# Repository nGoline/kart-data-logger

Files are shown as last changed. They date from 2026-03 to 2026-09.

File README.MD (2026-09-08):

# ESP32 Kart Telemetry System

A telemetry and datalogging system for open-track go-karts, built around a single
steering-wheel-mounted ESP32 display board that handles everything: GPS
acquisition, lap timing, dashboard rendering and SD logging.

> **Note:** earlier revisions of this project split the work between a
> helmet-mounted logger node and the display, linked over ESP-NOW. That helmet
> node proved unreliable at the track and has been removed — the display is now
> the only node.

## System Architecture

Single target: the **Display Dashboard Node**.

* **Board:** JC3248W535N (ESP32-S3, AXS15231B QSPI panel)
* **Role:** GPS acquisition, lap detection, UI dashboard, and SD logging.
* **Features:**
  * GPS from ATGM336 (default) or u-blox M9, wired directly to the board.
  * Live speed, G-force, satellite count and display battery state.
  * Finish-line based lap detection with best/previous lap deltas.
  * Telemetry logged to SD card per recording session.
  * Optional MPU6050 IMU for speed filtering and steering angle.

### Build targets in `platformio.ini`

Both targets build the same application (`src/main_display.cpp`) and differ only
in the panel driver backend:

* `env:display_gfx` — Arduino_GFX backend (`lib/DisplayGFX`). **Default.**
* `env:display` — esp_lcd backend (`lib/DisplayBSP`). Fallback.

The Arduino_GFX backend is the default because it resolves a QSPI panel wedge
seen with the esp_lcd path.

## Key Technical Features

* **Modular GPS provider** abstraction in `GpsManager`.
* **Finish-line lap detection** in `LapManager`, driven by GPS position.
* **`fix_stride.py` prebuild patch** for SquareLine Studio LVGL 9 image exports.
* **Display-wedge watchdog** — a 5s task watchdog on `loopTask` turns a panel
  wedge into a fast auto-reset instead of a permanent freeze.
* **Charge mode** to keep the board from eating the charger's current budget.
* **Optional IMU support** to improve speed filtering and live telemetry.

## Charge mode

The charger's current is shared between the board and the cell, so a running
dashboard slows charging considerably. Charge mode parks the device:

* Stops the recording session and closes the GPS UART.
* Drops the CPU to 80 MHz (the floor for stable USB-CDC — don't go lower).
* Swaps to a minimal charge screen and blanks the backlight after 15s.

It is **only ever entered manually**, from the `CHARGE MODE` button on the
config screen. Nothing enters it automatically, so bench testing and debugging
are unaffected.

While parked: tap anywhere to wake the backlight and read the battery for
another 15s; press `RESUME` to leave. Resuming re-probes the GPS, which takes a
couple of seconds.

> **Whether the GPS actually sleeps depends on which one is fitted.** Charge mode
> calls `gps.standby()` and leaves the UART open so `wake()` can talk to it.
> On the **ATGM336** that is a quiesce, not a sleep: the RF front end has no
> software power-down at all, so it keeps drawing ~25-40 mA and standby only cuts
> it to GPS-only at 1Hz with NMEA muted. On the **u-blox M9** it is a real
> power-down — `UBX-RXM-PMREQ` software backup, woken by traffic on the module's
> RX pin. Coming back may cost a cold start if the module's V_BCKP does not hold
> the BBR, but the configuration itself is in flash and survives either way.

> **The percentage reads high while charging.** With no power-path charger the
> sense divider sits on the charger rail, so it measures the cell terminal
> voltage *under charge*, which is well above its resting value — expect a
> jump downward when you unplug. It's shown as `~94%` to mark it approximate;
> the voltage below it is the number to trust.

The charge screen and the config-screen button are both built at runtime in
`lib/UiHelper/uiHelper.cpp` rather than exported from SquareLine, so
re-exporting `lib/ui/` will not wipe them.

## Hardware Requirements

* JC3248W535N display board
* GPS module wired to `RX=6` / `TX=7` — ATGM336, or a u-blox M9 such as the Matek
  M9N-5883. The ATGM336 runs on 3V3; the M9N-5883 wants 4~5.5V, so its VCC belongs
  on the IP5306 5V rail, not the board's 3V3.
* Optional MPU6050 IMU
* microSD card formatted FAT32

## Software Dependencies

Built with PlatformIO.

* `lvgl/lvgl` (v9.x)
* `moononournation/GFX Library for Arduino` (`display_gfx` only)
* `mikalhart/TinyGPSPlus`
* `ElectronicCats/MPU6050`

## GPS Providers

`GpsManager` supports two providers. Nothing older than these is supported — the
NEO-6M-era 9600-baud fallback is gone.

* **ATGM336 provider** (current default)
  * Enabled with `-D GPS_PROVIDER_ATGM336`.
  * 10Hz.
  * Configured over CASIC text commands (`$PCAS`), which are never acked, so the
    module cannot report whether a setting took. It also cannot be put to sleep:
    `$PCAS12` standby is a 5L-only feature and this is a 5N.
* **u-blox M9 provider** — targets the M9 generation (NEO-M9N), e.g. the Matek
  M9N-5883.
  * Leave `-D GPS_PROVIDER_ATGM336` out of the build flags.
  * 25Hz.
  * Probes 115200 then 38400 (the M9 default), and moves the port to 115200.
  * Sleeps for real in charge mode — `UBX-RXM-PMREQ` software backup, armed to
    wake on UART RX traffic.
  * Configured over binary UBX, which *is* acked, and the provider reads the
    dynamic model / rate / power mode back at boot and logs `BEFORE:` and
    `AFTER:` lines. Legacy `UBX-CFG-*` messages are deprecated on generation 9
    but still supported; they are removed on generation 10, so a future module
    means porting `configureUblox()` to `UBX-CFG-VALSET`.
  * **Speaks `UBX-NAV-PVT`, not NMEA.** All NMEA output is disabled. One 92-byte
    frame per epoch carries position at 1e-7° (~1.1cm), Doppler ground speed,
    UTC, `numSV`, `fixType`, `pDOP`, `hAcc` and `sAcc` — less traffic than
    GGA+RMC and strictly more information, as one coherent snapshot instead of a
    position from one sentence stitched to a speed from another. It also makes the
    four-constellation problem vanish: per-system duplication of GSA/GSV was an
    NMEA artefact, and UBX has no talker IDs to multiply.
  * `hasFix()` therefore uses the receiver's own verdict — `gnssFixOK`,
    `fixType == 3`, and `hAcc` within bounds — rather than the `sats >= 4 &&
    HDOP <= 3` heuristic the NMEA path had to guess with.
  * **TinyGPSPlus is unused on this path.** It stays in `lib_deps` for the
    ATGM336, and static-archive linking drops it (and the unreferenced provider)
    from the image. It is still compiled every build, so a break in either
    provider still fails the build.

The flag lives in `[display_common] -> build_flags_base`, so it applies to both
build targets at once.

### Fix rate

ATGM336 runs at **10Hz**, u-blox M9 at **25Hz** — the receiver's ceiling with all
four constellations. GGA+RMC at 25Hz is ~36kbaud of the 115200 the port is set to,
so the link has room to spare. 40ms epochs also land on exact centisecond values
(`.00`/`.04`/`.08`…), which matters because NMEA timestamps are centiseconds and
anything finer would round.

The rate buys **log resolution**, which is the point — at 100 km/h, 25Hz puts a
sample every 1.1m instead of every 2.8m. It buys much less for lap times, because
`LapManager` intersects the finish gate with the segment between consecutive fixes
and interpolates the crossing millisecond along it, so the reported time never
quantised to the fix interval in the first place.

To sustain 25Hz, `LogManager` holds the log file open for the whole session and
`flush()`es once a second, rather than reopening and closing it per row (25 FAT
directory updates a second is where a slow card starts stalling). The trade is
durability: an abrupt power-off now costs up to a second of the lap instead of a
single sample. The telemetry queue is 40 frames for the same reason — ~1.6s of
headroom at 25Hz, so a card stall doesn't drop rows.

### GPS wiring

The GPS UART pins are set by `GPS_STANDALONE_RX` / `GPS_STANDALONE_TX` in
`[display_common]`, currently `6` and `7`.

Watch for collisions when changing these: `GPIO5` carries the battery sense
divider (`DISPLAY_BATT_ADC` in `src/main_display.cpp`), and `GPIO18`/`GPIO17`
are the IMU's I2C pins when `ENABLE_IMU` is set.

## Session button

A momentary switch wired between `SESSION_BUTTON_PIN` and GND starts and stops
recording without touching the screen — the dash is on the steering wheel and the
touch target is small with gloves on.

* **Tap** — runs the same start gesture as the on-screen START button: the
  full-screen 3-2-1 overlay with the track name and a CANCEL, then the session
  begins (GoPro rolls, active track's finish line re-applied).
* **Hold 3 s** — stops it, counting `3 - 2 - 1` on the dashboard. Let go early and
  nothing happens.

The start overlay is parented to whatever screen is showing rather than to the
config screen, so it is visible when the physical button fires it from the
dashboard. Tapped from the config screen those are the same object, so the
on-screen button is unchanged.

The button is inert in charge mode — `loop()` returns before the display lock is
taken there, which is the point of that mode.

A tap while a session is already running does nothing: stopping is deliberately
the harder gesture, since an accidental stop costs the rest of the session.

Configured in `platformio.ini`:

| Flag | Default | Notes |
|---|---|---|
| `SESSION_BUTTON_PIN` | `6` | Comment out to build without a button |
| `SESSION_BUTTON_HOLD_MS` | `3000` | Hold time for the stop |
| `SESSION_BUTTON_ACTIVE_HIGH` | off | Set when the switch goes to 3V3 rather than GND |
| `SESSION_BUTTON_DEBOUNCE_MS` | `25` | Raise it if a long lead registers phantom taps |

Wire the switch between the pin and **GND** by default. If the spare wire in the
loom is a 3V3 instead, wire it pin-to-3V3 and set `SESSION_BUTTON_ACTIVE_HIGH` —
that swaps the internal pull-up for a pull-down, so the idle level is still the
released one. The pin is pulled to the idle rail either way and never left
floating: a floating input on a wire run out to a steering wheel picks up enough
to toggle on its own, and a broken wire then reads as *released* rather than as a
stuck press.

GPIO 6 is the ATGM336's old RX pad, already broken out and in the loom now that
the GPS is on 17/18. Other free pins: 7, 9, 10, 14, 15, 16, 41, 42. Avoid 0, 3,
45, 46 (strapping), 19/20 (native USB), 43/44 (UART0) and 26-37 (flash/PSRAM).

The state machine (`lib/SessionButton`) holds no GPIO or LVGL state, so it is
replayed on the host by `tools/lapreplay/sessionbutton.cpp` — bounce windows, a
release a millisecond short of the hold, and the `millis()` wrap, none of which
can be produced reliably with a thumb.

## Filesystem & Storage

The display reads and writes to a **FAT32 microSD** card. No files need to be
pre-populated — the display creates what it needs on first boot — but the files
below may be edited on a computer for configuration.

#### `/config.ini` (auto-created)

Stores display preferences. Created with defaults on first boot if absent.

```ini
# Kart Data Logger Configuration
theme=dark          # dark | light
selected_track=0    # index into tracks.ini
```

#### `/health.csv` (auto-created, only when something goes wrong)

Appended across every session, one row per second in which the telemetry queue
had no room for a frame:

```
epoch,log,dropped_total,dropped_delta
```

**An empty or absent file is the good news** — it means no row was ever lost. Any
row in it means the card could not keep up with the fix rate and the matching
`log_N.csv` is missing samples, so the file is worth checking after a race rather
than watching the serial log, which is unreachable with the dash on a wheel.

`epoch` comes from the GPS-synced system clock, so it lines up with the `epoch`
column in the telemetry file; before the first fix it degrades to uptime.

#### `/tracks.ini` (optional, user-created)

Defines named tracks with GPS finish-line coordinates. The display reads this at
boot and populates the track selector in the UI. If absent, no tracks are
preloaded.

```ini
# Kart track configurations
count=2

0_name=Kartódromo Granja Viana
0_left_lat=-23.60488969
0_left_lon=-46.83622658
0_right_lat=-23.60493793
0_right_lon=-46.83641597

1_name=My Track
1_left_lat=0.00000000
1_left_lon=0.00000000
1_right_lat=0.00000000
1_right_lon=0.00000000
```

#### `/log_N.csv` (auto-created per session)

Telemetry session logs. A new numbered file is created each time a recording
session starts.

```
epoch,speed,totalGForce,gForceX,gForceY,steering_angle,sats,lat,lng,fix,pdop,hacc,sacc
```

The last four are the receiver's report on its own fix, and are **zero on the
ATGM336** — NMEA carries no equivalent, so zero means "not reported", not "perfect".

| column | meaning |
| --- | --- |
| `fix`  | `0` no fix, `2` 2D, `3` 3D, `5` time only. Never `1`/`4` (dead reckoning) — that is NEO-M9V silicon, not M9N. |
| `pdop` | position dilution of precision |
| `hacc` | horizontal accuracy estimate, metres, ~1σ |
| `sacc` | speed accuracy estimate, m/s |

`hacc` is the useful one for analysis: it does not make a position better, it tells
you which samples to distrust. Around 0.7-1.5m under open sky, climbing near
buildings and in the first seconds after a cold start. A lap time interpolated
between two 12m samples is not a lap time to trust to hundredths.

These columns are **appended**, never inserted, so everything in `tools/` keeps
working — those read by column name or by a fixed `sscanf` prefix. A CSV derived
from GoPro footage simply lacks them.

Note `lat`/`lng` are written at 7 decimal places (~1.1cm) rather than 6 (~11cm),
which is what `UBX-NAV-PVT` actually resolves.

## Setup & Installation

1. Clone this repository.
2. Open it in VSCode with PlatformIO.
3. Edit the UI using the SquareLine Studio project files in `UIDesign/`.
4. Export the UI to `/lib/ui/` and let `fix_stride.py` patch LVGL image metadata during build.
5. Flash the firmware: `tools/flash.sh` (see below).
6. Insert a FAT32 microSD card into the display. A default `config.ini` is created on first boot.

### Flashing

`upload_port` in `platformio.ini` is pinned to `/dev/cu.usbmodem1101`, which is one
machine's enumeration — the same board comes up under a different name elsewhere and
`pio run -t upload` then fails on a port that isn't there. `tools/flash.sh` finds the
board by USB `VID:PID` instead and passes it with `--upload-port`, which overrides the
pinned value:

```bash
tools/flash.sh              # default env, confirm, then upload
tools/flash.sh -m           # ...and open the serial monitor afterwards
tools/flash.sh -e display   # the esp_lcd fallback env
tools/flash.sh -p /dev/cu.usbmodem101   # skip discovery
tools/flash.sh -y           # no confirmation prompt (also FLASH_YES=1)
tools/flash.sh -- -v        # anything after -- goes to `pio run`
```

Before uploading it prints the port, env and `FW_VERSION`, and warns if the tree is
dirty — `FW_VERSION` is `git describe --tags --always --dirty` and shows on the setup
screen, so it is easy to flash uncommitted edits by accident. If more than one board is
attached it lists the candidates and asks for `-p`.

`pio run -e display_gfx -t upload` still works if the pinned port happens to be right.

## Dormant libraries

These libraries are no longer part of the build — nothing includes them — but
they are kept in `lib/` because they may be useful again:

* `EspNowManager` + `Shared/EspNowProtocol.h` message types — the board-to-board radio link.
* `ErrorLogManager` — LittleFS error capture and transfer.
* `AudioManager`, `VoiceParser` — I2S playback and spoken number/lap announcements.
* `PowerManager` — button-driven hibernate and power gating.
* `FakeGps` — CSV replay for development without GPS hardware.

`Shared/EspNowProtocol.h` is still compiled: `TelemetryMsg` is the record the
display passes between the UI, the lap manager and the SD log task.

## Design files

Design files are included under the `hardware/` folder.

### 3D Models

I've used Fusion to design 3D models for the custom enclosures and mounts. These
are located in `hardware/3d-models/` and exported as `.f3d` and `.3mf` files.
You can open and modify these in Fusion or any compatible 3D modeling software.

## Visual Reference

The repository includes module photos in the `images/` folder.

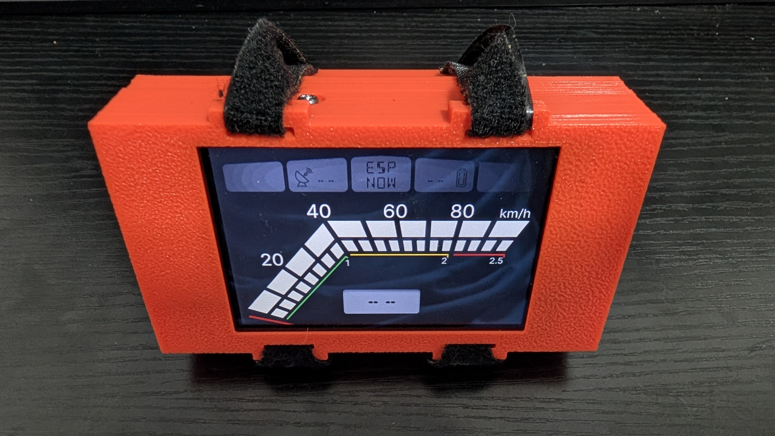
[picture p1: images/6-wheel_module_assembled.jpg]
Wheel module assembled


## Notes

* The display firmware owns the whole pipeline: GPS, lap timing, UI and SD logging.
* Lap detection only runs while a recording session is active.

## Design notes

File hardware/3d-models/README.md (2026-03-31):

# 3D Models

This folder contains the Fusion 360 source models and assembly exports used to validate the kart display enclosure and its subcomponents.

## Included files

* `Display.f3d` — main display enclosure model.
* `Display Assembly.3mf` — assembly export showing how the display, rear cover, battery support, and wheel holder fit together.
* `Battery.f3d` — battery pack model and holder details.
* `4056 Battery Charger.f3d` — USB-C charging board model and placement.
* `GPS.f3d` — GPS enclosure model.
* `MP6050.f3d` — IMU module model.

## Design intent

The primary part is `Display.f3d`. The other models were created to build the assembly and verify that all pieces fit correctly.

## Mounting and fastening

* The display board is held in place by small pegs that fit into matching bosses in the enclosure.
* The back cover is pressed onto the display body by rear cover pegs and then bolted in place.
* The back cover uses eight `M3X3X5` heat inserts and eight `M3x6` bolts.
* The helmet GPS enclosure uses four `M2.5x6mm` bolts and four `M2.5x4x4mm` heat inserts.
* The GPS holder fits the ATGM336 module and a `25x25mm` antenna.

## Battery and charging

* The rear cover supports a `LGBH4ZB4857` 2000mAh battery.
* The battery is sourced from a Dell Latitude 5490 battery pack, which contains three of these cells.
* A `4056` 1A USB-C charging board is integrated into the back cover space.

## Wheel holder and battery cover

* The battery cover / wheel holder assembly is not permanently fixed to the back cover.
* It is held in place by velcro loops that attach from the front of the display case, securing the assembly without rigid fasteners.
* The wheel holder is fixed to the rear plate using four `M3X3X5` heat inserts and four `M3x6` bolts.
* This wheel holder section can be modified for different kart wheel sizes, or multiple sizes can be printed and swapped without redesigning the entire case.

## IMU placement

* The IMU is mounted to the front of the battery back plate using double-sided tape.

## Notes

* Use the Fusion 360 `.f3d` files for source edits and design updates.
* The `.3mf` assembly file is useful for fit verification and export to compatible printing workflows.
* Confirm fastener lengths and insert positions before printing if you modify the enclosure geometry.

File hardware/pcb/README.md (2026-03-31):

# PCB Documentation

This folder holds PCB design documentation for the kart telemetry system.

There are two PCB variants documented here:

* `hardware/pcb/SMD/README.md` — the surface-mount device (SMD) PCB version.
* `hardware/pcb/Perfboard/README.md` — the through-hole perfboard version.

Use this root README as the entry point for the PCB designs and follow the subdirectory README files for variant-specific details.

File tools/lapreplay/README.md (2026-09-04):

# Lap replay harness

Offline test rig for finish-line detection. Turns a GoPro's telemetry into the
logger's own CSV format and replays it through the **real** `lib/LapManager`
compiled for the host — so lap detection can be validated without going to the
track.

Nothing here is part of the firmware build. `tools/` is outside `build_src_filter`
and `lib/`, so PlatformIO never sees it.

`make` also builds **`delta`**, which checks the *live* lap delta: the number
the dash hero panel shows continuously, from matching each fix against a
reference lap's recorded trace. See "Testing the live delta" below.

`make` also builds **`navpvt`**, an offset-level check on the real
`UbloxGpsProvider::update()` — it feeds synthetic `UBX-NAV-PVT` frames through a
byte-queue serial stub and asserts what the provider decodes. Run it after touching
that provider: it decodes by explicit byte offset, and a wrong offset does not crash,
it produces plausible telemetry that is silently wrong. It covers the field offsets,
the `hasFix()` gates (2D rejected, `hAcc` bound), checksum rejection, mm/s→km/h
scaling, and a frame split at every byte boundary — that last one being the real 25Hz
failure mode, where a message straddles two `update()` calls because the UART buffer
drained mid-frame.

## Why a GoPro

GoPro MP4s carry a GPMF metadata track alongside the video. On a HERO8 that is
GPS at ~18 Hz and accelerometer/gyro at ~200 Hz — denser than the ATGM336's
10 Hz, already timestamped in UTC, and free if you were filming anyway.

## Usage

```sh
# 1. extract telemetry -> CSV (no ffmpeg/exiftool needed; parses the MP4 directly)
python3 gpmf_to_csv.py ../../video/GH011973.MP4 GH011973.csv

# 2. build the harness
make

# 3. replay against a finish line: <csv> <leftLat> <leftLng> <rightLat> <rightLng>
./replay GH011973.csv -23.60488969 -46.83622658 -23.60493793 -46.83641597
```

`make VERBOSE=1` surfaces `LapManager`'s own `log_d()` gate diagnostics
("Approaching Gate", "Gate Missed!", "VALID CROSSING") which are compiled out by
default.

### Testing lap *timing*

A single crossing only starts the clock — it produces no lap time. If the clip is
a near-closed loop, stitch it into synthetic laps:

```sh
python3 gpmf_to_csv.py ../../video/GH011973.MP4 looped.csv --repeat 4
./replay looped.csv -23.60488969 -46.83622658 -23.60493793 -46.83641597
```

Each reported lap should equal the printed span exactly; any drift is a bug in
the crossing interpolation.

### Testing the live delta

The hero panel's delta comes from `LapManager`'s reference trace: the lap in
progress is recorded as position plus elapsed time, the session's best lap is
kept as the reference, and every fix is matched to the nearest point on it. A
wrong match does not crash, it produces a plausible number that is quietly
attached to the wrong piece of track, which is the worst way to find out at a
circuit. `delta` catches that offline:

```sh
python3 gps_raw_to_log.py --out /tmp/session.csv ../data/gps_raw_GH0*1974.csv
./delta /tmp/session.csv -23.605392 -46.836045 -23.605442 -46.836251
```

The `err` column is the check. At the line the live delta must agree with the
arithmetic one (this lap's time minus the reference lap's), because the two are
the same comparison reached by completely different routes: one by matching
1,000-odd fixes against a polyline, the other by subtracting two crossing
timestamps. On the 12-lap fixture they agree to within 22 ms on every lap, and
the harness exits non-zero if any lap drifts past 250 ms.

`moves` and `held` say how many fixes changed the number and how many repeated
it. A delta that "moves" once per lap would be the old behaviour, and the
point of the whole feature is that it does not. `--dump` emits
`epoch,lap,elapsed_ms,delta_ms` per fix for plotting the trace of a lap.

The trace buffers are allocated by the caller, here and in the firmware, which
is what lets `LapManager` stay host-clean: on the dash they come from PSRAM, in
this harness from `new[]`.

## Column mapping

Output matches `LogManager::task`'s `/log_N.csv` exactly:

```
epoch,speed,totalGForce,gForceX,gForceY,steering_angle,sats,lat,lng
```

| column | source | notes |
|---|---|---|
| `epoch` | `GPSU` | absolute UTC, 1 Hz; the 18 Hz `GPS5` samples are interpolated between stamps |
| `speed` | `GPS5` 2D speed | m/s → km/h |
| `totalGForce` | `ACCL` magnitude | orientation-independent, always correct |
| `gForceX/Y` | `ACCL` axes | **see caveat below** |
| `steering_angle` | — | always `0.0`; a camera cannot know this |
| `sats` | `GPSF` | GPMF has no satellite count, only fix type and DOP. Emitted as `12` on a 3D fix, else `0`, because `LogManager` and `LapManager` treat `sats == 0` as unusable |
| `lat`/`lng` | `GPS5` | 6 dp, ~0.11 m resolution |

**Axis caveat:** GPMF's accelerometer axis order depends on camera mount
orientation (see the `ORIN`/`ORIO` tags). The X/Y assignment is a starting guess —
verify against a known corner before trusting `gForceX`/`gForceY`. Raw accel also
peaks around 6 g from chassis vibration, so samples are averaged into each GPS
interval to damp it.

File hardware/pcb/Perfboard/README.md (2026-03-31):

# Through-Hole Perfboard Version

This folder is intended for the through-hole perfboard version of the kart PCB.

It should contain layout, wiring, and assembly information for a perfboard-based build alternative.

## Purpose

The perfboard variant is useful when a full custom PCB is not available or when hand assembly is preferred.

## Status

The actual through-hole layout files are not included yet. Add the perfboard schematic, board layout, and component placement documentation here when they are available.

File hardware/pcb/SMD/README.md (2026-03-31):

# SMD PCB Version

This folder contains the surface-mount board design files for the kart telemetry project.

Available files:

* `kart_smd.kicad_pcb` — SMD PCB layout.
* `kart_smd.kicad_sch` — schematic for the SMD board.
* `.history/` — KiCad project history and backups.

Use this variant when you want a compact, production-ready board with surface-mounted components.

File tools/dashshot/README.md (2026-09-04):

# dashshot — see the dashboard before you flash it

Renders the dashboard to PNG on your machine, so a layout change can be looked
at in a second or two instead of a two-minute build, a flash, and a squint at
the panel.

```sh
cd tools/dashshot
make shots        # -> out/dash_*.png
```

## Why this and not a mock

It compiles the **real** `lib/DashV2/ui_dash2.c` and the **real** generated
`lib/DashFonts` faces against LVGL's software renderer, with no display driver:
LVGL draws into a 480x320 RGB565 buffer and the tool writes that buffer out. So
glyph metrics, flex layout, alignment offsets and overflow all behave exactly as
they do on the device.

That distinction is the entire point. A hand-written HTML mock would agree with
whatever arithmetic you did about label widths; this disagrees with you when you
are wrong. The `5_widest` scene exists for precisely that — it renders the widest
string the lap box can ever hold (`8:88.888`, all wide digits) so "it fits" is an
observation rather than a calculation.

## Scenes

| file | what it is for |
|---|---|
| `1_cold` | session up, no reference lap: the blank delta and muted lap box |
| `2_faster` | mid-lap, up on the best, one sector closed |
| `3_slower` | down on the best, two sectors closed |
| `4_best` | purple SESSION BEST at the line |
| `5_widest` | the widest strings every box can hold, for overflow |
| `6_day` | the day palette, so the second theme is not left untested |

Add one by copying a block in `dashshot.c` — it is a straight sequence of calls
to `ui_dash2`'s public API followed by `settle_and_shoot()`.

## Two things it cannot show

**No status bar.** `ui_dash2` deliberately does not build one: the firmware keeps
a persistent bar on `lv_layer_top()` so it survives across screens, and it is
assembled in `lib/UiHelper` from SquareLine's export. So the top 26 px are empty
here, and the REC / DEMO cell, the battery, GPS, CAM and WIFI cells do not
appear. Geometry below it is unaffected — upstream's bar is 26 px at y=0 too, so
everything else lands where it does on the device.

**Byte order matters.** `lv_conf.h` sets `LV_COLOR_16_SWAP=1` because the esp_lcd
backend needs it, so LVGL renders byte-swapped RGB565 and `DisplayGFX.cpp` undoes
the swap in its flush callback. `dashshot.c` does the same, guarded the same way.
Getting it wrong is not subtle but it is misleading: the near-black background
comes out dark olive and every colour looks like a palette bug.

## Build notes

LVGL comes from the PlatformIO dependency tree
(`.pio/libdeps/display_gfx/lvgl`), so run a firmware build at least once first.
Its objects are cached under `build/`, so the first `make` takes a minute and
every one after it takes about a second. `make clean-local` rebuilds just the
dash and the tool; `make clean` drops the LVGL objects too.

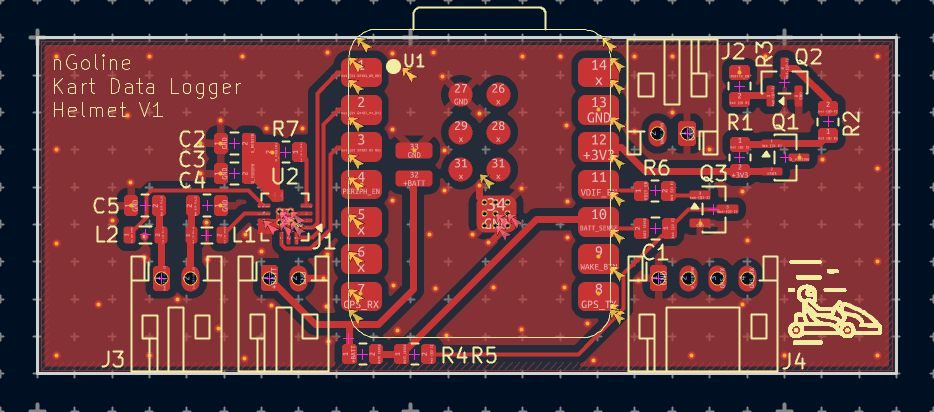
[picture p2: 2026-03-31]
images/smd_pcb_design.png

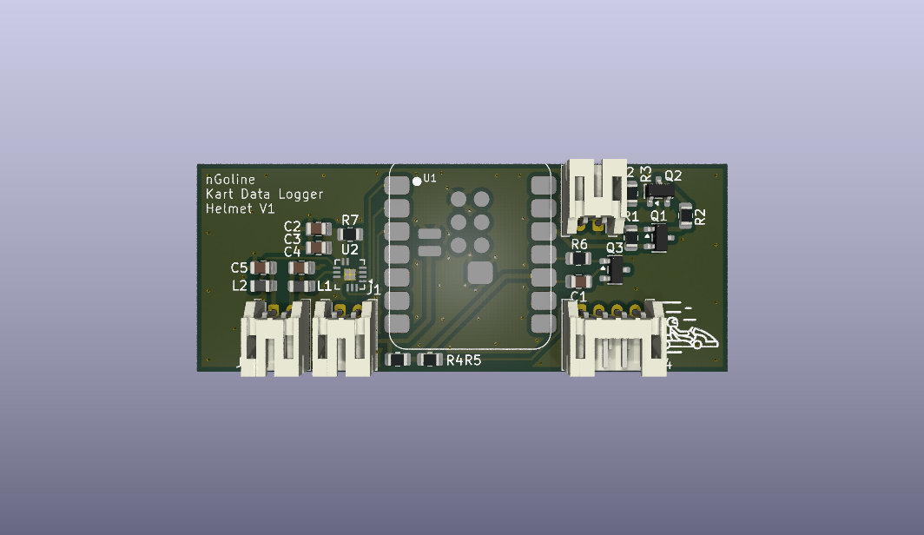
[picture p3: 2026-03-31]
images/smd_pcd_3d_design.png

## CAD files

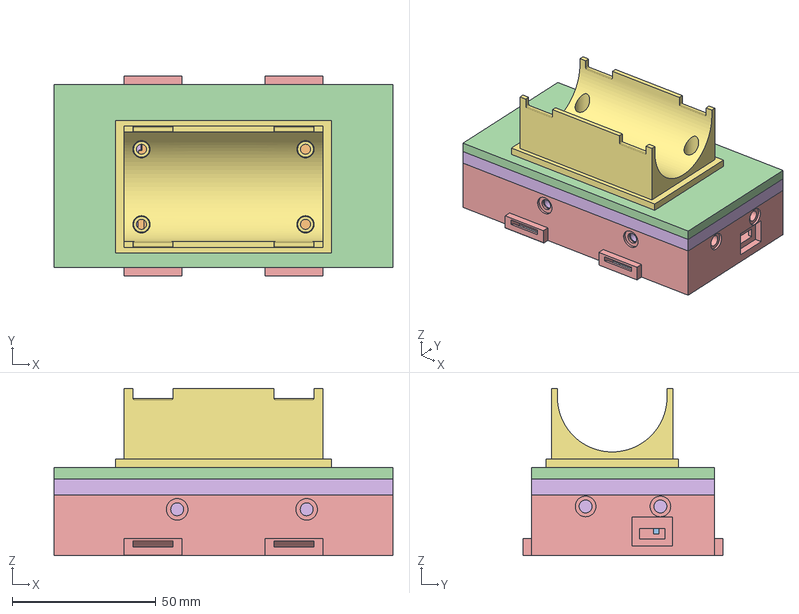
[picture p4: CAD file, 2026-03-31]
hardware/3d-models/Display Assembly.3mf
117.8 x 69.5 x 58.1 mm
display_BackCover
display_Body
display_Cover
display_WheelHolder

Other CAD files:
hardware/3d-models/4056 Battery Charger.f3d
hardware/3d-models/Battery.f3d
hardware/3d-models/Display.f3d
hardware/3d-models/GPS.f3d
hardware/3d-models/MP6050.f3d

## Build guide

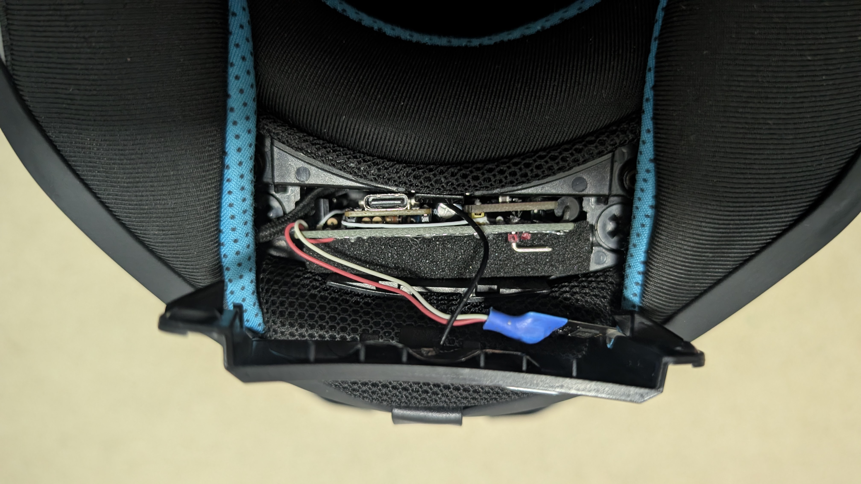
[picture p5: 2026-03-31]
images/2-helmet_breadboard_installation.jpg

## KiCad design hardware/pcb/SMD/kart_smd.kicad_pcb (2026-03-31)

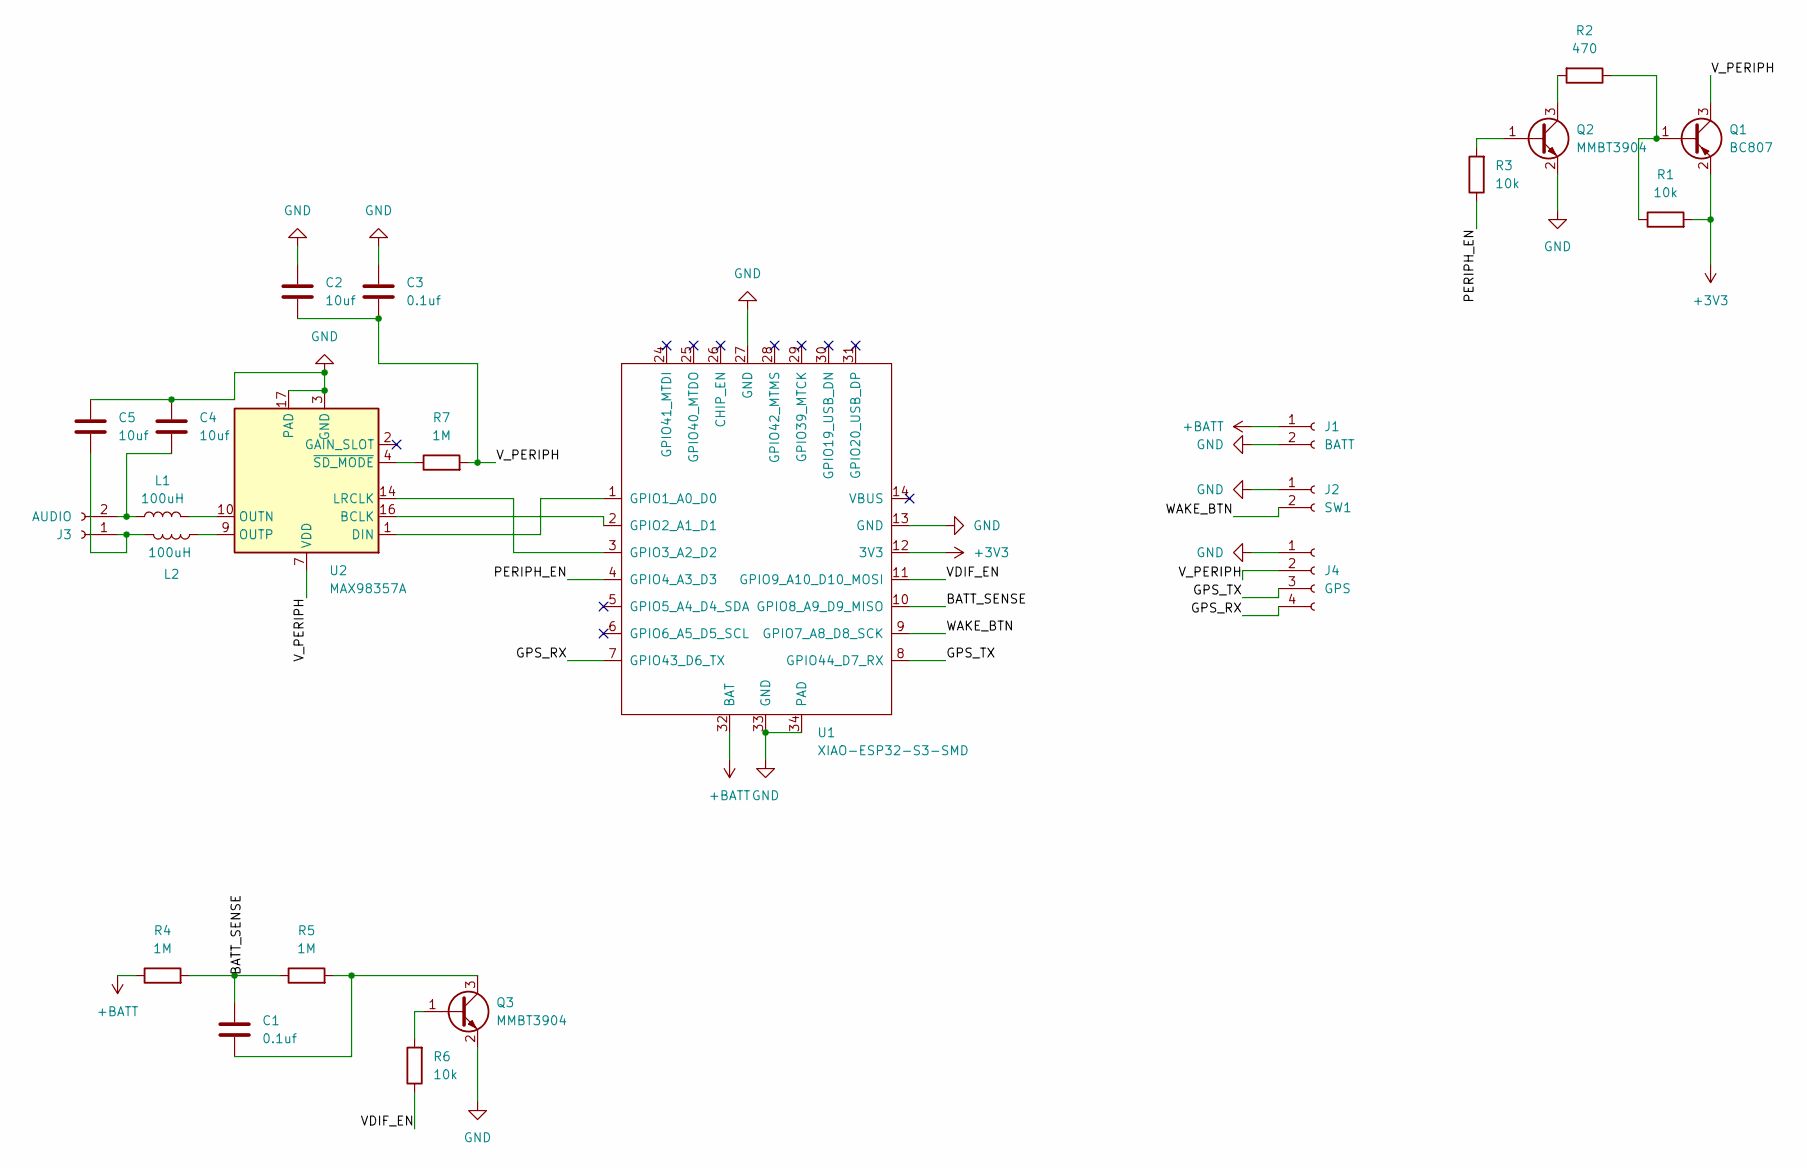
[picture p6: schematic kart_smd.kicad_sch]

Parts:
C1, C3: 0.1uf; C_0805_2012Metric
C2, C4, C5: 10uf; C_0805_2012Metric
J1: BATT; JST_PH_S2B-PH-K_1x02_P2.00mm_Horizontal
J2: SW1; JST_PH_S2B-PH-K_1x02_P2.00mm_Horizontal
J3: AUDIO; JST_PH_S2B-PH-K_1x02_P2.00mm_Horizontal
J4: GPS; JST_PH_S4B-PH-K_1x04_P2.00mm_Horizontal
L1, L2: 100uH; L_0805_2012Metric
Q1: BC807; SOT-23
Q2, Q3: MMBT3904; SOT-23
R1, R3, R6: 10k; R_0805_2012Metric
R2: 470; R_0805_2012Metric
R4, R5, R7: 1M; R_0805_2012Metric
U1: XIAO-ESP32-S3-SMD
U2: MAX98357A; TQFN-16-1EP_3x3mm_P0.5mm_EP1.23x1.23mm_ThermalVias

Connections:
+3V3: Q1.2 (E), R1.2, U1.12 (3V3)
+BATT: J1.1, R4.1, U1.32 (BAT)
/BATT_SENSE: C1.2, R4.2, R5.1, U1.10 (GPIO8_A9_D9_MISO)
/GPS_RX: J4.4, U1.7 (GPIO43_D6_TX)
/GPS_TX: J4.3, U1.8 (GPIO44_D7_RX)
/PERIPH_EN: R3.1, U1.4 (GPIO4_A3_D3)
/VDIF_EN: R6.1, U1.11 (GPIO9_A10_D10_MOSI)
/V_PERIPH: C2.2, C3.2, J4.2, Q1.3 (C), R7.2, U2.7 (VDD), U2.8 (VDD)
/WAKE_BTN: J2.2, U1.9 (GPIO7_A8_D8_SCK)
GND: C2.1, C3.1, C4.1, C5.1, J1.2, J2.1, J4.1, Q2.2 (E), Q3.2 (E), U1.13 (GND), U1.27 (GND), U1.33 (GND), U1.34 (PAD), U2.3 (GND), U2.11 (GND), U2.15 (GND), U2.17 (PAD)
unnamed: C5.2, J3.1, L2.2
unnamed: C4.2, J3.2, L1.1
unnamed: Q1.1 (B), R1.1, R2.1
unnamed: Q2.1 (B), R3.2
unnamed: Q2.3 (C), R2.2
unnamed: Q3.1 (B), R6.2
unnamed: C1.1, Q3.3 (C), R5.2
unnamed: U1.1 (GPIO1_A0_D0), U2.1 (DIN)
unnamed: U1.2 (GPIO2_A1_D1), U2.16 (BCLK)
unnamed: U1.3 (GPIO3_A2_D2), U2.14 (LRCLK)
unnamed: L1.2, U2.10 (OUTN)
unnamed: L2.1, U2.9 (OUTP)
unnamed: R7.1, U2.4 (~SD_MODE)

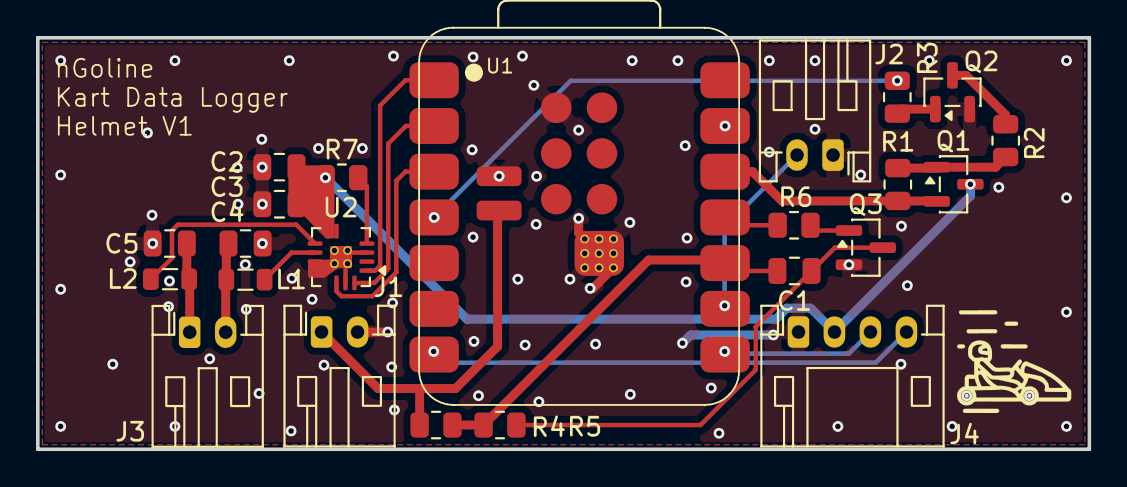
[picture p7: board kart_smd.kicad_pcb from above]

Board: 2 copper layers, 58.4 x 22.9 mm, 23 parts (0 on the bottom side), 23 nets.

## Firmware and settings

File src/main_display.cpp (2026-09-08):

#include <Arduino.h>
#include "esp_task_wdt.h"   // display-wedge safety net (used throughout)
#include "esp_system.h"     // esp_reset_reason

// QSPI flush telemetry from lib/DisplayBSP/lv_port.c (C linkage). Reported once a
// second below via log_w so it surfaces at CORE_DEBUG_LEVEL=WARN.
extern "C" {
    extern volatile uint32_t lvgl_port_frame_drops;
    extern volatile uint32_t lvgl_port_max_stall_us;
}

// Library includes from our new /lib folder
#include "LogManager.h"
#include "EspNowProtocol.h"
#include "uiHelper.h"
#include "ui_theme.h"   /* ui_session_clicked() — the start countdown overlay */
#include "BatteryManager.h"
#include "SessionButton.h"
#include "ConfigManager.h"
#include "LapManager.h"
#include "DemoTrack.h"
#include "GpsManager.h"

#if defined(ENABLE_GOPRO)
#include "GoProManager.h"
#endif

#if defined(ENABLE_WEB_PORTAL)
#include "WebPortal.h"
#endif

#include "SessionBrowser.h"
#include "LogBuffer.h"
#include "LogScreen.h"

// Opens the on-device session review screens. Called from the config screen,
// already in LVGL context — the browser loads a placeholder and repaints before
// the (slow) SD read, so the press feels immediate.
extern "C" void ui_helper_open_sessions(void) {
    sessionBrowser.openList();
}

// Opens the log screen. Reached from the config screen and from the dashboard
// alert banner. Renders out of LogBuffer's RAM ring, so unlike the session
// browser there is no slow read to defer — it can run in LVGL context.
extern "C" void ui_helper_open_logs(void) {
    logScreen.open();
}

#if defined(ENABLE_IMU)
#include "ImuManager.h"
#include "CalibrationManager.h"

#define I2C_SDA 18
#define I2C_SCL 17
#endif

const uint8_t timeBetweenImuReads = 10; // ms between IMU reads (100 Hz)

// --- GLOBAL STATE ---
LogManager logManager;
UiHelper   uiHelper;
LapManager lapManager;

GpsManager gps(GPS_STANDALONE_RX, GPS_STANDALONE_TX);

#if defined(ENABLE_GOPRO)
GoProManager goPro;
#define GOPRO_UI_INTERVAL_MS 500
static uint32_t lastGoProUiMs = 0;
#endif

#if defined(ENABLE_WEB_PORTAL)
WebPortal webPortal;
#define WEB_PORTAL_UI_INTERVAL_MS 1000
static uint32_t lastWebUiMs = 0;

// Called from the config-screen button (LVGL context). start() brings up the
// SoftAP and HTTP server, which takes a moment — acceptable here because the
// user just pressed a button and the portal task does the serving.
extern "C" void ui_helper_toggle_wifi(void) {
    if (webPortal.isRunning()) {
        webPortal.stop();
#if defined(ENABLE_GOPRO)
        goPro.resumeRadio();
#endif
        uiHelper.setWifi(false, 0, nullptr);
        return;
    }

    // WiFi needs ~50 kB of internal DRAM and cannot use PSRAM; NimBLE is
    // holding a comparable amount, so the BLE stack stands down first.
    // Otherwise esp_wifi_init fails with ESP_ERR_NO_MEM.
#if defined(ENABLE_GOPRO)
    goPro.suspendRadio();
#endif
    bool up = webPortal.start();
    if (!up) {
#if defined(ENABLE_GOPRO)
        goPro.resumeRadio();      // give it back, we did not need it after all
#endif
        uiHelper.setWifiError();  // say so on the button rather than sit silent
        return;
    }
    String wip = webPortal.ip();
    uiHelper.setWifi(true, webPortal.clients(), wip.c_str());
}
#else
extern "C" void ui_helper_toggle_wifi(void) {}
#endif

// Latest assembled telemetry frame. Written by loop() from the local GPS (plus
// IMU when enabled), consumed by syncUI() for the dashboard and the SD log.
static TelemetryMsg telemetry = {};
static bool newTelemetryAvailable = false;

#if defined(ENABLE_IMU)
ImuManager imu;
CalibrationManager calibManager(imu);
ImuData latestImuData = {0};
bool imuReady = false;
uint32_t lastImuReadMs = 0;
#endif

// Display battery: BAT+ → 68k (683) → IO5 → 100k (01D) → GND (always-on divider)
// Theoretical ratio is 1.68; the ADC reads low (~40k source impedance starves its
// sample-and-hold), so it is fitted to a multimeter instead. To re-fit: scale by
// meter/reported, on battery only — with USB in the node is the charger rail.
// ponytail: gain-only fit, exact at ~4.0V. If it reads high near 3.5V, take a point
// down there and go two-point (gain + offset).
#define DISPLAY_BATT_ADC 5
#define DISPLAY_BATT_READ_INTERVAL_MS 5000
BatteryManager displayBattery(DISPLAY_BATT_ADC, 0xFF, 1.7269f);
static uint32_t lastDisplayBattReadMs = 0;

#if defined(SESSION_BUTTON_PIN)
/* Physical session button: tap to start, hold to stop. Pin and polarity are build
 * flags because both are properties of the wiring loom, not of the firmware — see
 * the pin table in the README before moving it.
 *
 * Default: switch between the pin and GND, idle pulled up, pressed reads LOW.
 * Define SESSION_BUTTON_ACTIVE_HIGH to wire it to a spare 3V3 instead, which
 * flips the internal pull to a pull-down so the idle level is still the released
 * one. Either way the pin is never left floating: a floating input on a wire
 * running to a steering wheel picks up enough to toggle on its own. */
#if defined(SESSION_BUTTON_ACTIVE_HIGH)
#define SESSION_BUTTON_ACTIVE_LEVEL HIGH
#define SESSION_BUTTON_IDLE_MODE    INPUT_PULLDOWN
#else
#define SESSION_BUTTON_ACTIVE_LEVEL LOW
#define SESSION_BUTTON_IDLE_MODE    INPUT_PULLUP
#endif

#if !defined(SESSION_BUTTON_DEBOUNCE_MS)
#define SESSION_BUTTON_DEBOUNCE_MS 25
#endif

static SessionButton sessionButton(SESSION_BUTTON_HOLD_MS,
                                   SESSION_BUTTON_DEBOUNCE_MS);
#endif

// Smoothing & Metrics
float displaySpeed = 0;
float targetSpeed = 0;
const float lerpFactor = 0.20f;
static uint32_t lastHealthReportMs = 0;

// Lap state — updated inside syncUI()
static uint8_t s_lapCount = 0;

/* Reference-trace storage for the live lap delta. LapManager allocates
 * nothing itself, so the buffers are handed to it from here, in PSRAM next to
 * the log ring rather than the scarce internal heap. */
#define LAP_TRACE_POINTS LapManager::kRecommendedTracePoints
static LapTracePoint *s_traceRef = nullptr;
static LapTracePoint *s_traceCur = nullptr;

static void initLapTrace() {
    size_t bytes = sizeof(LapTracePoint) * LAP_TRACE_POINTS;
    s_traceRef = (LapTracePoint *)ps_malloc(bytes);
    s_traceCur = (LapTracePoint *)ps_malloc(bytes);
    if (!s_traceRef || !s_traceCur) {
        /* No fallback to the internal heap: 24 KB there is worth more than a
         * live delta, and LapManager without buffers just reports no delta. */
        free(s_traceRef); free(s_traceCur);
        s_traceRef = s_traceCur = nullptr;
        log_w("Lap trace: %u bytes of PSRAM unavailable, live delta disabled",
              (unsigned)(bytes * 2));
        return;
    }
    lapManager.setTraceBuffers(s_traceRef, s_traceCur, LAP_TRACE_POINTS);
}

/* ============================================================================
 * DEMO MODE
 * Drives the real dashboard from synthetic telemetry, so the whole live path
 * runs exactly as it does on track. Nothing is written to the card, so a demo
 * leaves no session behind. It installs its own gates — the selected track may
 * be nowhere near, or have no split gates at all — and puts the real track's
 * back on the way out.
 * ========================================================================= */
static DemoTrack s_demo;
static bool s_demoMode = false;

// Set from LVGL callbacks, consumed in loop() — same rule as charge mode.
static volatile bool s_demoEnterPending = false;
static volatile bool s_demoExitPending  = false;
static volatile bool s_demoSkipPending  = false;
/* A finish-line crossing found while draining demo frames, handed to syncUI so
 * the header and the best-lap flash still run in one place. At most one can
 * happen per pass: a pass advances about a second of simulation and a lap is
 * forty. */
static bool s_demoLapDone = false;

extern "C" void ui_helper_enter_demo_mode(void) { s_demoEnterPending = true; }
extern "C" void ui_helper_exit_demo_mode(void)  { s_demoExitPending  = true; }
extern "C" void ui_helper_demo_skip_lap(void)   { s_demoSkipPending  = true; }

/* Lap timing runs for a real session or a demo. The log enqueue deliberately
 * does not consult this — it stays gated on the session alone. */
static inline bool timingActive() {
    return logManager.isSessionActive() || s_demoMode;
}

// Push a track's split gates into LapManager. Must follow setFinishLine(),
// which clears them — the splits belong to a track, so a new finish line
// invalidates them.
static void applySectorGates(const TrackConfig *t) {
    if (!t) return;
    FinishLine s1 = { t->s1.left_lat, t->s1.left_lon, t->s1.right_lat, t->s1.right_lon };
    FinishLine s2 = { t->s2.left_lat, t->s2.left_lon, t->s2.right_lat, t->s2.right_lon };
    lapManager.setSectorGates(t->s1.usable() ? &s1 : nullptr,
                              t->s2.usable() ? &s2 : nullptr);
}

// Install a track into LapManager: finish line first, then the splits it
// clears. Every path that re-points lap timing goes through here, because the
// two calls have to happen in that order.
static void applyTrack(const TrackConfig *t) {
    if (!t || !t->left_valid || !t->right_valid) return;
    FinishLine fl = { t->left_lat, t->left_lon, t->right_lat, t->right_lon };
    lapManager.setFinishLine(fl);
    applySectorGates(t);
}

static const TrackConfig *selectedTrack() {
    return configManager.getTrack((int)configManager.getSelectedTrack());
}

static void enterDemoMode() {
    if (s_demoMode) return;
    if (logManager.isSessionActive()) {
        /* Refused rather than silently stopping the session: a demo is not
         * worth ending a recording for. */
        log_w("DEMO: a session is recording — stop it first");
        return;
    }

    s_demo.begin();

    FinishLine g[DemoTrack::GATE_COUNT];
    s_demo.gates(g);
    lapManager.setFinishLine(g[DemoTrack::GATE_END]);
    lapManager.setSectorGates(&g[DemoTrack::GATE_S1], &g[DemoTrack::GATE_S2]);

    s_lapCount = 0;
    s_demoMode = true;

    /* Under the display lock: this runs in loop(), not in LVGL context. */
    bsp_display_lock(0);
    uiHelper.setLap(0, "", "");
    uiHelper.setDemoState(true);
    bsp_display_unlock();

    log_i("DEMO: started on the synthetic oval");
}

static void exitDemoMode() {
    if (!s_demoMode) return;
    s_demoMode = false;
    s_lapCount = 0;

    /* Put the real track back. setFinishLine() also clears the reference trace,
     * so the demo's laps cannot become the delta reference for a real session. */
    applyTrack(selectedTrack());

    bsp_display_lock(0);
    uiHelper.setDemoState(false);
    uiHelper.setLap(0, "", "");
    uiHelper.setLiveDelta(0, false);
    uiHelper.setDeltaBar(0, false);
    uiHelper.setLapClock(0);
    bsp_display_unlock();

    log_i("DEMO: stopped, real track restored");
}

// ============================================================================
// CHARGE MODE
// Entered only from the CHARGE MODE button on the config screen — never
// automatically — so debugging and bench testing are unaffected.
// Parks the device so the charger's current budget goes to the cell instead of
// the load: GPS off, session stopped, CPU down, backlight on a timeout.
// ============================================================================
#define CHARGE_CPU_MHZ              80     // USB-CDC needs >= 80MHz; do not go lower
#define NORMAL_CPU_MHZ              240
#define CHARGE_BACKLIGHT_TIMEOUT_MS 15000  // both on entry and after a tap
#define CHARGE_BATT_INTERVAL_MS     5000
#define CHARGE_LOOP_DELAY_MS        50

static bool s_chargeMode         = false;
static bool s_chargeBacklightOn  = false;
static uint32_t s_chargeBacklightOnMs = 0;
static uint32_t s_chargeBattReadMs    = 0;

// Set from LVGL event callbacks, consumed in loop(). The callbacks must stay
// trivial: entering/leaving charge mode blocks for seconds, which would wedge
// the LVGL task while it holds the display lock.
static volatile bool s_chargeEnterPending = false;
static volatile bool s_chargeExitPending  = false;
static volatile bool s_chargeTouchPending = false;

extern "C" void ui_helper_enter_charge_mode(void) { s_chargeEnterPending = true; }
extern "C" void ui_helper_exit_charge_mode(void)  { s_chargeExitPending  = true; }
extern "C" void ui_helper_charge_screen_touched(void) { s_chargeTouchPending = true; }

// ============================================================================
// DISPLAY-WEDGE SAFETY NET (ALWAYS ON) - "indestructible" recovery.
// The AXS15231B QSPI panel write (panel_axs15231b_draw_bitmap) can occasionally
// hang the LVGL task while it holds the display lock, which would otherwise
// freeze the whole UI forever (screen + touch + serial dead). The spin cannot
// be safely unstuck in place, so we guarantee recovery instead: a short Task
// Watchdog on loopTask converts a wedge into a fast auto-reset (~5s) and the
// dash comes straight back.
// Timeout keeps headroom over legitimate slow paths (SD writes) so it only ever
// fires on a genuine *infinite* wedge, never on a transient stall.
// ============================================================================
#define DISPLAY_WDT_TIMEOUT_MS 5000
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
void loop() {
    uint32_t now = millis();

    esp_task_wdt_reset();   // feed the display-wedge watchdog (always on)

    // Transitions run here, never in LVGL callback context.
    if (s_chargeEnterPending) {
        s_chargeEnterPending = false;
        if (!s_chargeMode) enterChargeMode();
    }
    if (s_chargeExitPending) {
        s_chargeExitPending = false;
        if (s_chargeMode) exitChargeMode();
    }
    if (s_demoEnterPending) { s_demoEnterPending = false; enterDemoMode(); }
    if (s_demoExitPending)  { s_demoExitPending  = false; exitDemoMode();  }
    if (s_demoSkipPending) {
        s_demoSkipPending = false;
        /* Ignored outside a demo: the lap clock is a live readout there, not a
         * control, and there is no synthetic lap to skip. */
        if (s_demoMode) {
            s_demo.skipToNextLap();
            log_i("DEMO: skipping to the next lap");
        }
    }

    // Ahead of everything below on purpose: charge mode is a parking state, so
    // it must not fall through to session analysis (a multi-second SD stream)
    // or the dashboard repaint. Both would defeat the point of the mode.
    if (s_chargeMode) {
        serviceChargeMode(now);
        delay(CHARGE_LOOP_DELAY_MS);
        return;
    }

    // Session analysis runs here, deliberately before the display lock is
    // taken: streaming a log takes many seconds, and doing it while holding the
    // lock would block this task and trip the watchdog.
    sessionBrowser.service();

    // Flush captured log lines to SD. Here for the same reason as the line
    // above: it touches the card, and must not run under the display lock.
    logBuffer.service();

#if defined(ENABLE_IMU)
    if (imuReady) {
        float currentSteering = calibManager.getSteeringAngle();

        if (calibManager.isDone() && (now - lastImuReadMs >= timeBetweenImuReads)) {
            latestImuData = imu.update(currentSteering);
            lastImuReadMs = now;
        }
    }
#endif

    /* Drain EVERY NAV-PVT frame, not one per pass. update() yields a single
     * frame per call now, so this loop logs all 25 per second even when a slow
     * LVGL or SD pass makes loop() itself run at 19Hz — which is exactly how a
     * measured session lost 24% of its rows without the health counter noticing,
     * the frames being discarded upstream of the queue. The UI still consumes
     * only the newest via newTelemetryAvailable; only the log needs all of them. */
    /* Demo mode substitutes for the receiver entirely. Same while-loop shape
     * as the real drain below, so a slow pass catches up.
     *
     * Unlike the real drain, every frame goes into LapManager here rather than
     * only the newest surviving to syncUI. A skip emits up to 25 frames in one
     * pass, and handing over just the last of them leaves consecutive fixes a
     * second of simulation apart - about 22 m - which steps straight over a
     * 14 m gate and loses the lap. */
    while (s_demoMode && s_demo.update(now, telemetry)) {
        newTelemetryAvailable = true;
        if (timingActive() && lapManager.processTelemetry(telemetry))
            s_demoLapDone = true;
    }

    while (!s_demoMode && gps.update()) {
        /* IMU removed — no accelerometer on this build. The g-force and gyro
         * fields stay in the message (and the CSV) as zeros so old sessions and
         * SessionBrowser keep parsing; a future 9-DoF refills them. */
        telemetry.type        = MSG_TELEMETRY;
        telemetry.speedKmph   = (float)gps.getSpeed(0.0f, 0.0f);
        telemetry.gForceX     = 0.0f;
        telemetry.gForceY     = 0.0f;
        telemetry.totalGForce = 0.0f;
        telemetry.gyroZ       = 0.0f;
        telemetry.lat         = gps.getLat();
        telemetry.lng         = gps.getLng();
        telemetry.sats        = (uint8_t)gps.getSatellites();
        telemetry.hasFix      = gps.hasFix() ? 1 : 0;
        telemetry.timestamp   = gps.getEpochMs();

        // Fix quality, zeroed on providers that cannot report it (the ATGM336).
        GpsFixInfo fix        = gps.getFixInfo();
        telemetry.fixType     = fix.fixType;
        telemetry.pdop        = fix.pdop;
        telemetry.hAccM       = fix.hAccM;
        telemetry.sAccMps     = fix.sAccMps;

        /* Enqueue HERE, once per frame. This used to live in syncUI() behind the
         * newTelemetryAvailable flag, which is a one-slot handoff: whatever
         * arrived between UI passes was overwritten and never reached the queue.
         * Zero timeout still, so a full queue drops the row rather than blocking
         * the UI — but now that is a real drop the health counter can see. */
        if (LogManager::logQueue != NULL && logManager.isSessionActive()) {
            if (xQueueSend(LogManager::logQueue, &telemetry, 0) != pdTRUE) {
                logManager.noteDroppedFrame();
            }
        }

        newTelemetryAvailable = true;
    }

    // Display battery ADC read — done before the display lock to avoid blocking LVGL
    static uint8_t cachedDisplayBattPct = 255;
    static uint8_t lastDisplayBattPct = 255;
    if (now - lastDisplayBattReadMs >= DISPLAY_BATT_READ_INTERVAL_MS) {
        lastDisplayBattReadMs = now;
        cachedDisplayBattPct = (uint8_t)displayBattery.getPercentage();
        log_i("Display battery: %d%%", cachedDisplayBattPct);
    }

    /* GPS heartbeat. "GPS 0" on the dash says a fix is missing but not why, and
     * the difference matters: satellites climbing with fixType stuck at 0 is a
     * sky-view/cold-start problem and will come good if left alone; zero
     * satellites for minutes is an antenna, wiring or config problem and never
     * will. Logged unconditionally so a session that never got a fix leaves an
     * account of itself on the card. */
    static uint32_t lastGpsLogMs   = 0;
    static uint32_t lastGpsFrames  = 0;
    if (now - lastGpsLogMs >= 5000) {
        /* Measured NAV-PVT rate, not the rate we asked for. CFG-RATE is accepted
         * without complaint even when the receiver cannot sustain it, so the only
         * way to know we are really getting 25Hz is to count frames and divide. */
        uint32_t frames  = gps.getFrameCount();
        uint32_t elapsed = now - lastGpsLogMs;
        float    hz      = lastGpsLogMs && elapsed
                             ? (frames - lastGpsFrames) * 1000.0f / (float)elapsed
                             : 0.0f;
        lastGpsLogMs  = now;
        lastGpsFrames = frames;

        /* gps.update() is never called in demo mode, so the frame counter does
         * not move. Say so rather than reporting 0.0Hz, which reads as a dead
         * receiver. */
        if (s_demoMode) {
            log_i("GPS: DEMO MODE — synthetic telemetry, receiver not being read");
        } else {
            GpsFixInfo fi = gps.getFixInfo();
            log_i("GPS: sats=%lu fix=%u ok=%d pdop=%.1f hAcc=%.1fm rate=%.1fHz",
                  (unsigned long)gps.getSatellites(), (unsigned)fi.fixType,
                  fi.gnssFixOK ? 1 : 0, fi.pdop, fi.hAccM, hz);
        }
    }

    // Once-a-second health reporting
    if (now - lastHealthReportMs >= 1000) {
        lastHealthReportMs = now;

        // QSPI flush health: report dropped frames and the worst bus-idle wait in
        // the last second, then reset the stall high-water mark. A blink should line
        // up with either a frame_drops increment (hard skip) or a high max_stall.
        static uint32_t lastFrameDrops = 0;
        uint32_t drops = lvgl_port_frame_drops;
        uint32_t stallUs = lvgl_port_max_stall_us;
        lvgl_port_max_stall_us = 0;
        if (drops != lastFrameDrops || stallUs >= 8000) {
            log_w("[DISP] frame_drops=%lu (+%lu)  max_bus_stall=%lu us",
                  (unsigned long)drops, (unsigned long)(drops - lastFrameDrops),
                  (unsigned long)stallUs);
            lastFrameDrops = drops;
        }

        // Log rows the queue had no room for. Also persisted to /health.csv by the
        // log task, since serial is no use with the dash bolted to a steering wheel.
        static uint32_t lastLogQueueDrops = 0;
        uint32_t logDrops = logManager.droppedFrames();
        if (logDrops != lastLogQueueDrops) {
            log_w("[LOG] queue_drops=%lu (+%lu) — the card is not keeping up",
                  (unsigned long)logDrops,
                  (unsigned long)(logDrops - lastLogQueueDrops));
            lastLogQueueDrops = logDrops;
        }

#if defined(ENABLE_IMU)
        if (imuReady) {
            float steeringDeg = calibManager.getSteeringAngle();
            latestImuData = imu.update(steeringDeg);
            log_i("Steering: %.1f deg | G: %.2f", steeringDeg, latestImuData.gForce);
        }
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

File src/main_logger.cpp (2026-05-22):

#include <Arduino.h>
#include <LittleFS.h>
#include <esp_sleep.h>

// Modular Libraries
#include "EspNowManager.h"
#include "AudioManager.h"
#include "BatteryManager.h"
#include "PowerManager.h"
#include "VoiceParser.h"
#include "ErrorLogManager.h"
#include "EspNowProtocol.h"
#include "LoggingUtils.h"

#if defined(USE_FAKE_GPS)
#include "FakeGps.h"
#else
#include "GpsManager.h"
#endif

// --- HARDWARE CONFIG ---
#define I2S_DIN D0
#define I2S_BCLK D1
#define I2S_LRC D2
#define PERIPHERAL_ENABLE_PIN D3
#define GPS_RX RX
#define GPS_TX TX
#define OFF_BUTTON_PIN D8
#define BATT_ADC A9
#define VDIV_ENABLE_PIN D10
#define HOLD_TIME_MS 3000 // 3 seconds to turn off
#define BATTERY_READ_INTERVAL_MS 5000 // 5-10 seconds between battery samples

// --- GLOBAL MANAGERS ---
#if defined(USE_FAKE_GPS)
FakeGps fakeGps;
#else
GpsManager gps(GPS_RX, GPS_TX);
#endif

AudioManager audio(I2S_BCLK, I2S_LRC, I2S_DIN);
BatteryManager battery(BATT_ADC, VDIV_ENABLE_PIN, 2.0f);
PowerManager powerManager(OFF_BUTTON_PIN, PERIPHERAL_ENABLE_PIN, HOLD_TIME_MS, 1);
ErrorLogManager errorLogger;

// --- FREERTOS QUEUE & MUTEX ---
QueueHandle_t telemetryQueue;
static uint32_t lastBatteryReadMs = 0;
static uint8_t cachedBatteryPercentage = 0;

#if !defined(USE_FAKE_GPS)
// Wait for a newer IMU sample than lastUsedCounter. We keep a strict timeout so
// telemetry cadence remains stable even if a packet is dropped.
static bool waitForFreshImuSample(uint32_t &lastUsedCounter, ImuFeedbackMsg &imuOut, TickType_t maxWaitTicks) {
    TickType_t startTick = xTaskGetTickCount();

    while ((xTaskGetTickCount() - startTick) < maxWaitTicks) {
        uint32_t counter = 0;
        if (EspNowManager::getLatestImuFeedback(imuOut, counter) && counter > lastUsedCounter) {
            lastUsedCounter = counter;
            return true;
        }
        vTaskDelay(pdMS_TO_TICKS(2));
    }

    // Fallback to the latest known sample if a fresh one did not arrive in time.
    uint32_t counter = 0;
    if (EspNowManager::getLatestImuFeedback(imuOut, counter)) {
        lastUsedCounter = counter;
        return false;
    }

    imuOut = {};
    imuOut.type = MSG_IMU_FEEDBACK;
    return false;
}

static void monitorGpsDataFlow(bool gotFreshGpsSentence) {
    static uint32_t lastGoodGpsSentenceMs = 0;
    static uint32_t lastGpsTimeoutLogMs = 0;
    static bool gpsWasTimedOut = false;

    const uint32_t now = millis();
    const uint32_t startupGraceMs = 5000;
    const uint32_t gpsTimeoutMs = 3000;
    const uint32_t repeatLogMs = 30000;

    if (gotFreshGpsSentence) {
        lastGoodGpsSentenceMs = now;
        if (gpsWasTimedOut) {
            log_i("GPS data stream recovered.");
            gpsWasTimedOut = false;
        }
        return;
    }

    if (now < startupGraceMs) {
        return;
    }

    if (lastGoodGpsSentenceMs == 0) {
        if (now - lastGpsTimeoutLogMs >= repeatLogMs) {
            LOG_ERROR("GPS data timeout: no valid sentences received since boot.");
            lastGpsTimeoutLogMs = now;
            gpsWasTimedOut = true;
        }
        return;
    }

    if ((now - lastGoodGpsSentenceMs) >= gpsTimeoutMs && (now - lastGpsTimeoutLogMs) >= repeatLogMs) {
        LOG_ERROR_FORMATTED("GPS data timeout: no valid sentence for %lu ms.", (unsigned long)(now - lastGoodGpsSentenceMs));
        lastGpsTimeoutLogMs = now;
        gpsWasTimedOut = true;
    }
}
#endif

// --- TELEMETRY TASK (CORE 1) ---
void telemetryTask(void *pvParameters) {
    log_i("Telemetry Task started on Core 1");
    TickType_t xLastWakeTime = xTaskGetTickCount();
    #if defined(USE_FAKE_GPS)
    const TickType_t xFrequency = pdMS_TO_TICKS(200);
    #else
    const TickType_t xFrequency = pdMS_TO_TICKS(gps.getUpdateIntervalMs());
    #endif

#if !defined(USE_FAKE_GPS)
    uint32_t lastImuCounterUsed = 0;
    const TickType_t imuWaitBudget = (xFrequency > pdMS_TO_TICKS(10))
        ? (xFrequency - pdMS_TO_TICKS(10))
        : pdMS_TO_TICKS(0);
#endif

    for (;;) {
        #if defined(USE_FAKE_GPS)
        static TelemetryMsg msg;
        if (fakeGps.update(msg)) {
            log_d("Fake GPS Update: Epoch: %llu", msg.timestamp);
        } else {
            log_w("Fake GPS failed to update!");
        }

        #else
        // 1. Update Sensors
        bool gotFreshGpsSentence = gps.update();
        monitorGpsDataFlow(gotFreshGpsSentence);
        ImuFeedbackMsg imuFeedback = {};
        bool usedFreshImu = waitForFreshImuSample(lastImuCounterUsed, imuFeedback, imuWaitBudget);

        static uint32_t lastImuStaleWarnMs = 0;
        if (!usedFreshImu && (millis() - lastImuStaleWarnMs > 1000)) {
            log_w("IMU uplink stale; reusing latest sample for this frame.");
            lastImuStaleWarnMs = millis();
        }

        // 2. Push telemetry on the configured GPS cadence.
        TelemetryMsg msg;
        msg.type = MSG_TELEMETRY;
        msg.speedKmph = gps.getSpeed(imuFeedback.totalGForce, imuFeedback.gyroZ);
        msg.gForceX = imuFeedback.gForceX; // Lateral Gs for cornering
        msg.gForceY = imuFeedback.gForceY; // Longitudinal Gs for braking/accel
        msg.totalGForce = imuFeedback.totalGForce; // Combined G-Force magnitude for the needle
        msg.gyroZ = imuFeedback.gyroZ;
        msg.lat = gps.getLat();
        msg.lng = gps.getLng();
        msg.sats = (uint8_t)gps.getSatellites();
        msg.hasFix = gps.hasFix() ? 1 : 0;
        msg.timestamp = gps.getEpochMs();
        msg.helmetBattery = cachedBatteryPercentage;
        msg.usedFreshImu = usedFreshImu;
        #endif

        if ((millis() - lastBatteryReadMs) >= BATTERY_READ_INTERVAL_MS) {
            cachedBatteryPercentage = battery.getPercentage();
            lastBatteryReadMs = millis();
        }

        // 3. Send to Queue (Don't block if full, just drop the oldest)
        if (xQueueSend(telemetryQueue, &msg, 0) != pdPASS) {
            log_w("Telemetry Queue Full! Dropping packet.");
        }
        
        #if defined(USE_FAKE_GPS)
        delay(200); // Simulate GPS update delay
        #else
        // Wait for the next cycle
        vTaskDelayUntil(&xLastWakeTime, xFrequency);
        #endif
    }
}



void setup() {
    pinMode(LED_BUILTIN, OUTPUT);
    digitalWrite(LED_BUILTIN, HIGH);
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

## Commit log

2026-03-02 add gps and imu
2026-03-02 add audio cue and clean-up the project
    [partitions.csv]
2026-03-02 add gps speed filter and download endpoint
2026-03-04 move logic to modules - i2c don't work with 12s
    [esp32-3248S035C.csv, seed_xiao_esp32s3.csv]
2026-03-05 fix i2c vs i2s race condition; add more visual cues to the display;
    [main_display.cpp, main_logger.cpp]
2026-03-05 add helmet battery to display
2026-03-05 fix ublox startup code; update audio cues; refactor LapManager to for delta against last; add delta time to voice parser;
    [main_logger.cpp]
2026-03-06 update speed filter to get rid of false zeroes
2026-03-06 make esp-now logic more reliable; add debug logs; add logs to VoiceParser; fix AudioManager mutex;
    [real_car_ride.csv]
2026-03-09 update LapManager to use a line gate instead of a radius gate; add g force meter to display; limit battery to 99% on display.
    [real_car_ride.csv]
2026-03-21 add support to atgm336 gps+baidou module; add support for a latch circuit to turn on/off; add support for battery level cutt-off using the latch;
    [kart_data_logger.kicad_pcb, kart_data_logger.kicad_sch]
2026-03-24 updated KiCad project files; updated platformio.ini to change upload port and include MPU6050 library for IMU support; modified main_display.cpp to integrate IMU data handling and adjust telemetry ba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
    [kart_data_logger.kicad_pcb, kart_data_logger.kicad_sch]
2026-03-25 added ErrorLogManager class for managing error logs in LittleFS; introduced LoggingUtils.h for convenient logging macros; enhanced EspNowManager to handle error log transmission and acknowledgments; 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
    [main_display.cpp, main_logger.cpp]
2026-03-31 software version 1 used on a real kart on 2026/03/26
    [4056 Battery Charger.f3d, Battery.f3d, Display Assembly.3mf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]
2026-05-21 added new display board; removed esp32_smartdisplay in favor of local lib
    [JC3248W535N.csv]
2026-05-22 Replace the UI with a usable one.
    [esp32-3248S035C.csv]
2026-05-22 add track setup screen
2026-05-22 add new message to exchange track information with the helmet
2026-08-03 Stop the 'model' partition shadowing the filesystem partition
    'pio run -t uploadfs' reported success while writing to the wrong flash
    region, and LittleFS.begin() then failed with error -1 against a blank
    partition. Neither side reported a mismatch.
    PlatformIO picks the filesystem partition by scanning for type=data with
    subtype spiffs/fat/littlefs and keeping the LAST match - fetch_fs_size()
    in the platform's builder/main.py assigns without a break. The table had
    two such partitions:
    spiffs, data, spiffs, 0x610000, 0x700000 <- LittleFS.begin() mounts this
    model, data, spiffs, 0xD10000, 0x2E0000 <- uploadfs wrote here
    'model' is reserved space for a future offline voice model (li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
    [JC3248W535N.csv]
2026-08-03 Add bench replay: play a recorded session through the live telemetry path
    Lets lap detection, best lap and the delta pill be exercised indoors with
    no kart, no track and no GPS fix:
    pio run -e display_replay -t uploadfs (once)
    pio run -e display_replay -t upload
    ReplayManager reads the exact 9-column CSV LogManager writes and feeds
    TelemetryMsg into loop() in place of the GPS, so everything downstream is
    the real code path. It takes an fs::FS&, so the file can come off the SD
    card or - with REPLAY_FROM_FLASH, for when there is no card reader around
    - out of the board's LittleFS partition, flashed over the same USB cable
    as the firmware.
    Playback rate does not affect results. LapMana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
    [main_display.cpp]
2026-09-04 feat(fonts): make the dash faces tabular
    The Barlow Condensed faces came out of lv_font_conv proportionally spaced, so
    every digit had its own advance width and a changing readout jittered
    sideways as the digits under it changed. That is unreadable at a glance,
    which is the only way a dash gets read.
    tools/dashfonts/tabularise.py rewrites each glyph's advance and bearing to
    the widest digit's, so all ten digits occupy one column. It is idempotent and
    re-runnable against a regenerated face, and it reports the resulting metrics
    because the layout widths in lib/DashV2 are derived from them.
2026-09-04 feat(lap): live delta against a reference lap
    Lap timing could only report on a lap once it ended. This records the lap in
    progress as position plus elapsed time, keeps the best lap so far as a
    reference trace, and matches each fix to the nearest point on it, so the
    question becomes "against my best lap, where am I now" rather than only "how
    did that lap end".
    Also derived from the same trace:
    - a predicted lap time (the reference plus the delta being carried),
    - virtual splits: the reference is cut into equal slices of reference time
    and the delta is re-baselined at each one. A cumulative delta pegs the
    moment you have a real off and then says nothing about the corners that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
2026-09-04 test(lapreplay): offline check for the live lap delta
    A wrong reference-trace match does not crash, it produces a plausible number
    quietly attached to the wrong piece of track, and a circuit is an expensive
    place to discover that. delta replays a recorded session and checks the
    continuously matched delta against the arithmetic one (this lap's time minus
    the reference lap's) at every line crossing: the two are the same comparison
    reached by completely different routes, so they have to agree. It also
    reports how often the split delta runs past the bar's full scale, which is
    where the bar's scale figure comes from.
    The four harnesses now share shim/harness.h for lap-time formatting and for
    rea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
2026-09-04 feat(dash): Dash v2 live delta hero and sector rail
    Re-cuts the dashboard around the fact that nothing numeric can be read
    mid-corner:
    - the vs-best hero becomes a delta PANEL carrying a centre-zero bar
    alongside the cumulative number and a predicted lap time. The bar is
    split-relative, not cumulative, and is the only part of this readable
    without taking your eyes off the track: gaining grows right, losing grows
    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
2026-09-04 feat(demo): synthetic track for driving the dash
    A 630 m oval in metres about a centre near Kartodromo Granja Viana, driven at
    a pace model that warms up over the first few laps and varies both between
    laps and around each one. The shape is chosen, not arbitrary: a flat pace
    plus noise makes the first timed lap the fastest by luck and every later one
    slower, so the panel goes red and stays red and a demo never shows green or
    purple at all. It also carries sub-metre position jitter, because a
    perfectly smooth path advertises a steadiness the GPS cannot deliver and the
    live delta would read as a flat line.
    gates() lays the gate posts out as LapManager takes them. Which post is
    "left" and whic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
2026-09-04 feat(demo): DEMO mode on the device
    A DEMO button on the config screen drops straight to the dashboard and drives
    the whole live path (lap detection, sectors, the reference trace, the delta,
    the lap clock) from the synthetic track, so the dash can be shown or checked
    with the kart stationary. Nothing is written to the card: the log enqueue and
    the session state are untouched, so a demo leaves no session behind.
    It installs its own gates, because the selected track may be nowhere near or
    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
2026-09-04 test(dashshot): render the real dash to PNGs on the host
    Compiles lib/DashV2/ui_dash2.c and the real lib/DashFonts faces against
    LVGL's software renderer, so what comes out is the firmware's layout rather
    than an impression of it, and will disagree with you when a string is too
    wide for its box. Eight scenes cover the states that are awkward to reach on
    track: no reference lap yet, up, down, a lap thrown away while currently
    gaining, the session-best purple, a first timed lap with sectors that have
    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
2026-09-08 Stop the once-a-second health block re-logging a stale telemetry row
    A paste left a second copy of the per-frame enqueue inside the once-a-second
    health branch, where it re-sends whatever the last NAV-PVT left in `telemetry`.
    A session therefore picked up one duplicate row per second, carrying a timestamp
    it had already written — invisible to the health counter, which only counts
    queue-send failures.
    It also landed between a two-line comment and its own code, so the QSPI comment
    appeared to document the enqueue.
    The same paste doubled the GPS heartbeat; #29 has since removed that copy, so
    only the enqueue is left to delete here. Deletion only — the surviving copy, in
    the `while (gps.up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
    [main_display.cpp]
2026-09-08 Show the session countdown over whatever screen is up
    The start overlay was parented to ui_configscreen, which is where the only
    thing that could open it lived. The physical session button fires it from the
    dashboard, and an overlay hung on a screen that is not showing counts down
    invisibly and then starts a session the driver never saw confirmed.
    Parenting it to lv_screen_active() is the same object when the on-screen START
    button opens it from the config screen, so that path is unchanged. Guarded the
    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
2026-09-08 Start and stop a session from a physical button
    The dash is bolted to the steering wheel and the on-screen START is a small
    target with gloves on. A momentary switch on a spare GPIO gives the same two
    gestures without looking at the screen: tap to start, hold three seconds to
    stop, counting down on the dashboard while held.
    Stopping is deliberately the harder gesture. A tap while recording does
    nothing — an accidental stop costs the rest of the session, an accidental
    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
